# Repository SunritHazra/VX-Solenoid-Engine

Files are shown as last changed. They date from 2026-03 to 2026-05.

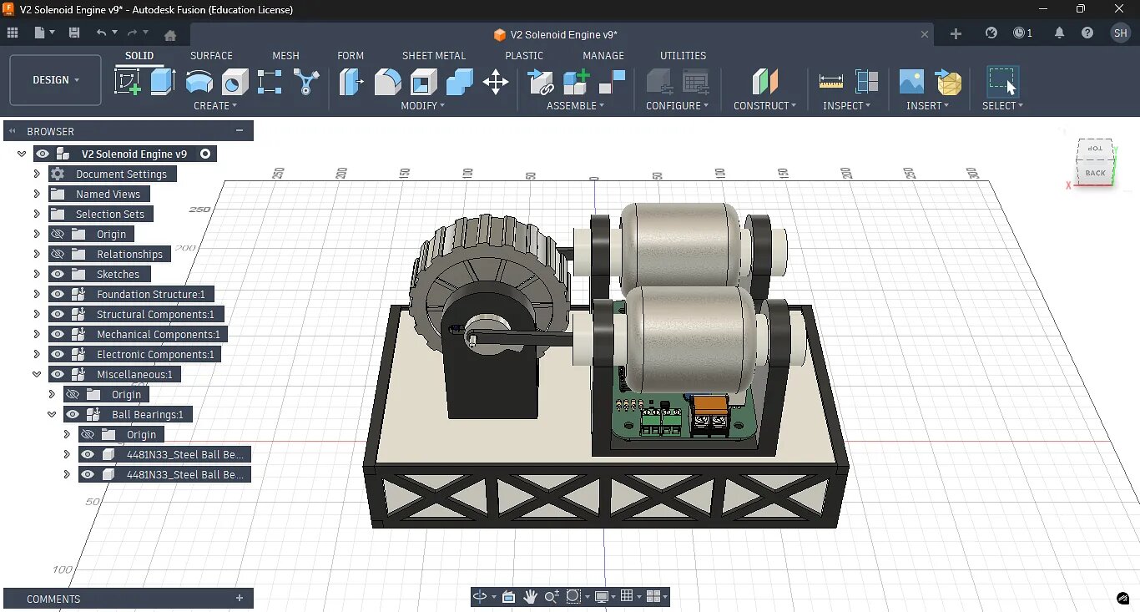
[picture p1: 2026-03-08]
Media/Workspace [2].jpg

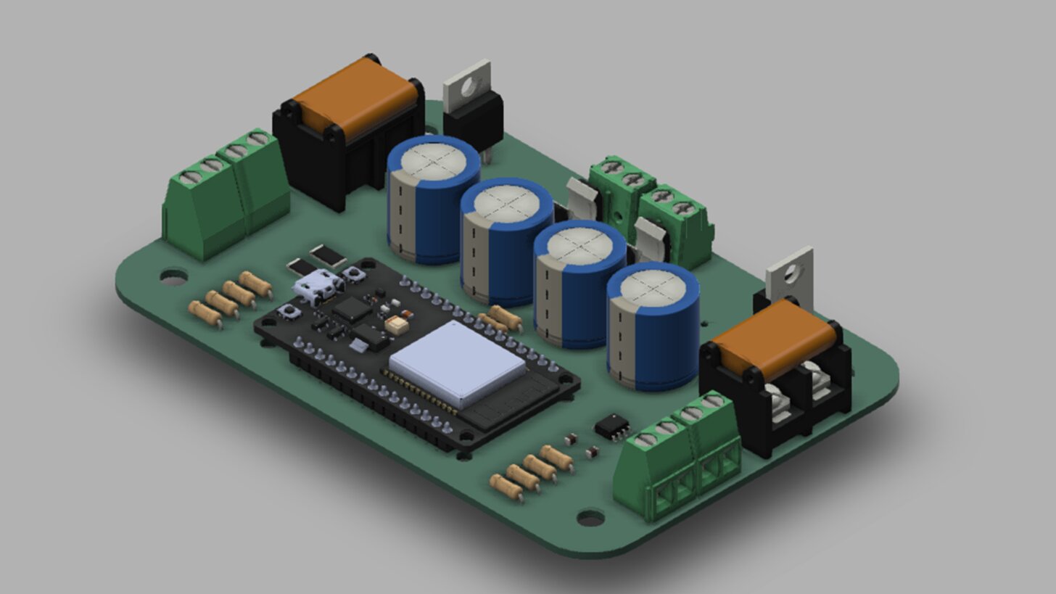
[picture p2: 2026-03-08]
Media/PCBA.jpg

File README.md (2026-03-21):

# VX Solenoid Engine — V2 Solenoid Engine

The project *"V2 Solenoid Engine"* is the second project of the long-term vision of "VX Solenoid Engine", which aims to build progressive solenoid engines with real engineering and proper planning. I have designed and completed the V1 Solenoid Engine before which was the prototype (you can find this in the first journal entry), and I had a partially designed a V10 Solenoid Engine with the help of an engineer from the United Kingdom (UK).

The V2 Solenoid Engine is a custom-designed electromechanical engine that converts electrical energy into rotational mechanical motion using electromagnetic actuation. Instead of combustion, the engine uses solenoids to generate magnetic fields that pull ferromagnetic plungers inside cylindrical sleeves, producing linear motion. This motion is transferred through a yoke and crankshaft mechanism that converts the linear movement into continuous rotation, similar to the working principle of a traditional piston engine.

This project is made with the aim of creating an engine that works efficiently, consistently and with coolness (not talking about thermal coolness), wirelessly. The ESP32 allows the user to run the engine at any speed, control the firing, etcetera. The engine is intended to be controllable through a laptop, a phone or any device wirelessly.

<center>
  V2 Solenoid Engine
</center>

We can often see solenoid engines nowadays as hobby toys, on platforms like YouTube, so what separates this project from those?  
Well, this has a PCB, MOSFET switching based on IR sensors, and it is made with performance and efficiency in mind. Please note that, efficiency is not the goal of this project, and this is an experimental setup to study electromagnetic actuation.

---

## Project Overview

The entire mechanical system is designed in **Autodesk Fusion** and the PCBA was designed in **KiCad**, with structural components and mechanical components (except flywheel) intended for MJF and SLS 3D printing, while control electronics are built around an ESP32-DEVKIT-V1 featuring ESP32-WROOM-32 and TCRT5000 IR position sensing. The engine is powered by a Mean Well LRS-450-24, that gives an output of 24 volts and 18.8 amperes.

The current design features a two-cylinder (V2) configuration sharing a single crankshaft, firing at 180 degrees, which improves rotational balance and reduces dead zones during operation. To control the engine’s timing, infrared reflective sensors monitor the position of the crankshaft and provide feedback to an ESP32 microcontroller, which determines when each solenoid should be energized (when the power should be on). A custom PCB handles the electronics (except the SMPS) required for switching the high-current solenoid coils, integrating MOSFET drivers, power regulation, and sensor interfaces while separating high-power and low-voltage logic systems for stability.

<p float="left">
  
  
</p>

The PCB has two different power inputs: one inputs 5V from a battery and one inputs 24V from the Mean Well LRS-450-24 (18.8 A). There are four more logical inputs (screw terminals): Two (4 pins) for each of the IR Sensor, for A, CATH, COLL and E. And there are two big output screw terminals, for each solenoid.



The PCB has no traces for the components through which 18.8 A flows. So, they have to be soldered pin-to-pin manually with thick wire suitable for that current like 18 AWG. I did this as I didn't want to make the traces too thick, probable to overheating and for safety reasons. And of course, I didn't want to use 2 oz thickness as it is expensive.

Together, the mechanical structure, sensing system, embedded controller, and power electronics form a programmable electromagnetic engine platform that allows experimentation with firing timing, control strategies, and electromechanical system design.

The engine demonstrates:
* Electromagnetic actuation
* Crankshaft-based mechanical power conversion
* Embedded timing control
* Hybrid manufacturing (3D printing + CNC)
* MOSFET Switching

**Note:** The flywheel has to be as heavy as possible, so it is better to CNC machine it despite the cost. A large flywheel is used to stabilize rotational inertia and maintain smooth motion between electromagnetic pulses.

---

## Core Concept

A solenoid is an electromechanical device that generates a magnetic field when current flows through its copper coil. A ferromagnetic plunger inside the solenoid is pulled toward the coil center. I just doubled it so that it looks more cool, and is more loud (really).



In this engine, this is what happens fundamentally:
1. A microcontroller (ESP32) activates the solenoid coil based on the position of the crank
2. Magnetic force pulls the ferromagnetic soft iron plunger
3. The plunger drives the connecting rod connected to the crankshaft
4. The crankshaft rotates
5. A flywheel smooths rotational motion
6. IR sensors detect crank position
7. The controller switches coils again

This cycle produces **continuous rotation**, with two pistons firing periodically at 180 degrees.

---

## Key Features

### Multi-Cylinder Mechanical Layout
The engine uses a **V2 configuration**, where two solenoid-driven cylinders operate on a shared crankshaft. This arrangement improves balance and reduces rotational dead zones, allowing smoother and more continuous motion.

### Electromagnetic Actuation
Each cylinder converts electrical energy into linear mechanical motion.  
Each cylinder contains:
* Copper coil winding
* Ferromagnetic plunger
* Linear motion sleeve

When current flows through the coil, a magnetic field is generated that pulls the plunger inward. The plunger’s movement converts magnetic attraction into controlled mechanical displacement.

### Crankshaft Mechanism
The crankshaft converts the linear motion of the plungers into rotational motion.  
Main components include:
* Crank pins
* Yokes
* Connecting linkages

The crankshaft geometry is intentionally compact and shortened to reduce friction losses and improve overall mechanical efficiency.

### Flywheel Stabilization
A large flywheel is mounted on the crankshaft to stabilize rotation.  
Its functions include:
* Increasing rotational inertia
* Reducing stalling between solenoid pulses
* Smoothing torque output

The flywheel helps maintain continuous rotation even when the solenoids are not actively pulling the plungers.

### Optical Position Sensing
The engine uses TCRT5000 infrared reflective sensors to detect crankshaft position.  
These sensors allow the control system to:
* Identify the rotational phase of the crankshaft
* Trigger solenoids at the correct timing
* Prevent mistimed coil activation

This sensing system transforms the engine from a passive mechanism into an actively controlled electromechanical system.

### Exoskeleton Structural Frame
The engine is supported by a rigid exoskeleton frame that holds the mechanical system together. The frame:
* Maintains alignment of cylinders
* Supports bearings and shaft components
* Prevents structural flexing
* Provides mounting points for sensors and electronics

The exoskeleton also allows modular modifications and easier maintenance.

---

## Mechanical Design

The mechanical system consists of several interacting components that convert electromagnetic actuation into rotational motion.

**Solenoid Cylinder Assembly**  
Each cylinder assembly contains:
* Coil housing
* Copper winding space
* Plunger sleeve
* Linear motion channel

The sleeve guides the plunger along a fixed path and ensures proper alignment during motion.

**Yoke Mechanism**  
The yoke connects the plunger to the crankshaft and transfers the linear motion.  
The yoke geometry was thickened to:
* Increase structural strength
* Provide sufficient space for coil windings
* Reduce mechanical deformation during operation

**Crankshaft**  
The crankshaft assembly includes:
* Crank throws
* Bearing supports
* Shaft core
* Flywheel mount

The crank geometry was designed to minimize rotational inertia and reduce mechanical drag.

**Structural Frame**  
The outer frame forms a rigid skeleton that supports the entire mechanical system.  
It provides mounting locations for:
* Cylinder assemblies
* Sensor placements
* Bearing supports
* Crankshaft alignment

---

## Electronics Architecture

The electronics system coordinates solenoid activation and processes sensor input.

**Microcontroller**  
The engine uses an ESP32 DevKit V1 microcontroller.  
Responsibilities include:
* Reading sensor signals
* Determining crankshaft position
* Controlling solenoid activation timing
* Executing control logic

The microcontroller also enables future expansions such as telemetry and advanced control algorithms.

**Position Sensors**  
Crankshaft position is detected using TCRT5000 IR reflective sensors.  
These sensors detect reflective markers attached to the rotating assembly and provide feedback necessary for correct timing of solenoid activation.

**Power System**  
The solenoid coils require high-current switching.  
The typical power architecture includes:
* 24 V power supply
* MOSFET switching stage
* Flyback protection diodes
* Capacitor banks for current stabilization

These components allow safe and efficient control of the solenoid currents.

---

## Manufacturing Plan

The project uses a hybrid fabrication approach, combining additive manufacturing with CNC machining, to balance cost and quality.

**3D Printed Components**  
Most structural components are designed for 3D printing, including:
* Engine frame
* Coil housings
* Yokes
* Sensor mounts
* Structural supports

Likely materials include:
* PLA for early prototyping
* PETG or ABS for stronger functional parts

**CNC Machined Components**  
Precision mechanical parts are planned to be manufactured using CNC machining, primarily through JLCMC.  
These parts include:
* Crankshaft
* Metal shafts
* Mechanical fasteners
* Possibly the flywheel

CNC machining provides better tolerances, strength, and durability for rotating components.

---

## Bill of Materials

A complete bill of materials is provided in **BOM.csv**.  
**Note:** Cart screenshots for Amazon, JLC, and Robu have been added in the design review already. Certain parts are sourced locally and paid for by the creator. Therefore, it is not possible to provide links for those items, and their costs are not included in the BOM requested from HCB.

---

## Firmware

Firmware source code is located at:  
**Firmware/V2 Solenoid Engine Firmware.cpp**

To flash the firmware:
1. Install the Arduino IDE.
2. Install the ESP32 board package.
3. Open the firmware file.
4. Select the correct ESP32 board and port.
5. Upload the firmware to the microcontroller.

After flashing, disconnect USB if powering externally.  
(For PlatformIO users: platformio.ini is included in the firmware folder.)

---

## Wiring

The full wiring schematic is provided here:  
**Media/V2 Solenoid Engine Schematic and Wiring.pdf**

**External Wiring Summary**  
Mean Well LRS-450-24 (+24V/GND) ─── 18 AWG Red/Black ─── J1 on PCB  
Solenoid + connected to +24V rail  
Solenoid - connected to MOSFET drains (manual 18 AWG)  
TCRT5000 sensors connected to their 4-pin headers (A, CATH, COLL, E) → GPIO34/35  
NTC thermistor connected to GPIO36  

**One very important note (again):** The PCB has no traces for the components through which 18.8 A flows. So, they have to be soldered pin-to-pin manually with thick wire suitable for that current like 18 AWG. I did this as I didn't want to make the traces too thick, probable to overheating and for safety reasons. And of course, I didn't want to use 2 oz thickness as it is expensive.

---

## Assembly and Operation Guide

This guide explains how to assemble, wire, and operate the V2 Solenoid Engine after printing the mechanical parts and manufacturing the PCB. Read the entire document before starting assembly.  
Please note that this guide is not completely reliable as the engine is not manufactured and assembled (as of March, 2026).

**Safety Information**  
This project uses 24V DC power, 18.8 A and contains fast moving mechanical parts.  
Follow these obvious precautions:  
- Never power the system while assembling the mechanical structure.  
- Keep fingers, hair, and loose clothing away from the crankshaft and flywheel while running.  
- Always use a regulated 24V power supply capable of supplying adequate current.  
- Ensure correct polarity when connecting the power supply.  
- Disconnect power immediately if components become excessively hot or behave unexpectedly.  
- Do not run the engine unattended.

**Required Components**  
All required components are listed in the Bill of Materials:  
**Bill of Materials/V2 Bill of Materials.csv**

**Tools Required**  
Typical tools required for assembly include:  
- Hex keys / Allen keys  
- Screwdrivers  
- Small wrench or socket set  
- Soldering iron (if assembling PCB manually)  
- Wire cutters and strippers  
- Threadlocker (recommended for high-vibration components)

**Mechanical Assembly**  
Follow these general steps to assemble the mechanical structure.  
#### 1. Frame Assembly  
- Assemble the main frame using the 3D printed structural parts.  
- Secure all frame pieces using the specified fasteners from the BOM.  
- Ensure the frame is rigid and square.  

#### 2. Crankshaft and Flywheel  
- Install the crankshaft into the frame supports.  
- Attach the flywheel to the crankshaft.  
- Verify that the shaft rotates freely with minimal friction.  

#### 3. Piston and Connecting Rod  
- Attach the connecting rod to the crankshaft.  
- Install the piston assembly.  
- Ensure the piston moves smoothly through its full range of motion.  

#### 4. Solenoid Mounting  
- Mount the solenoid in the designated bracket.  
- Align the solenoid plunger with the piston linkage.  
- Ensure the plunger moves freely and does not bind.  

#### 5. Final Mechanical Check  
- Rotate the crankshaft manually.  
- Confirm the full mechanism moves smoothly.  
- Verify that no parts collide or rub excessively.  

**PCB Installation**  
The PCB design files are located in:  
**PCBA/**  
Files included:  
- KiCad project  
- PCB layout  
- schematic  
- gerbers  
- STEP model  

**PCB Mounting**  
- Secure the PCB to the frame using the provided mounting holes.  
- Ensure the board is isolated from metal surfaces if necessary.  
- Maintain airflow around the board for cooling.  

---

## Operation

After the engine is fully assembled and wired:  
1. Ensure the crankshaft rotates freely.  
2. Verify all wiring connections.  
3. Connect the 24V power supply.  
4. Power the system.  

The firmware will drive the solenoid according to the programmed timing, causing the piston to actuate and rotate the crankshaft.  
The flywheel stabilizes the rotation and maintains momentum between solenoid pulses.

---

## Expected Behavior

When operating correctly:  
- The engine should begin rotating shortly after power is applied.  
- The flywheel should maintain smooth rotational motion.  
- The solenoid should actuate in synchronization with the crankshaft motion.  

Performance depends on:  
- Supply voltage stability  
- Mechanical friction  
- Solenoid characteristics  
- Firmware timing parameters  

---

## Troubleshooting

If the engine does not operate correctly:  

**Engine does not start**  
- Verify 24V power supply is connected.  
- Confirm correct wiring according to the schematic.  
- Ensure firmware was successfully flashed.  

**Solenoid does not activate**  
- Check PCB connections.  
- Verify the solenoid wiring.  
- Confirm correct ESP32 operation.  

**Engine stalls or runs poorly**  
- Inspect mechanical alignment.  
- Check for excessive friction.  
- Ensure solenoid plunger moves freely.  

**Excessive heat**  
- Disconnect power immediately.  
- Inspect wiring and current draw.  
- Verify the solenoid is not being continuously energized.  

---

## Additional Files

Relevant files in the repository:  
- **CAD/V2 Solenoid Engine v10.f3d** — Fusion 360 source model  
- **CAD/V2 Solenoid Engine v10.step** — universal 3D model  
- **PCBA/** — PCB design and manufacturing files  
- **Bill of Materials/V2 Bill of Materials.csv** — full component list  
- **Media/** — renders, PCB images, and wiring diagram  
- **Firmware/V2 Solenoid Engine Firmware.cpp** — ESP32 firmware (untested though)  

---

## Final Notes

Before operating the engine for extended periods, perform several short test runs to ensure mechanical stability and safe electrical behavior, because you are basically playing with 18.8 amperes and 24 volts, just for fun (maybe).  
Regularly inspect fasteners, moving components, and electrical connections to maintain safe operation, cause the thing vibrates, A LOT!
By the way, the safety guidelines are written based on real experience when the V1 Solenoid Engine was built.

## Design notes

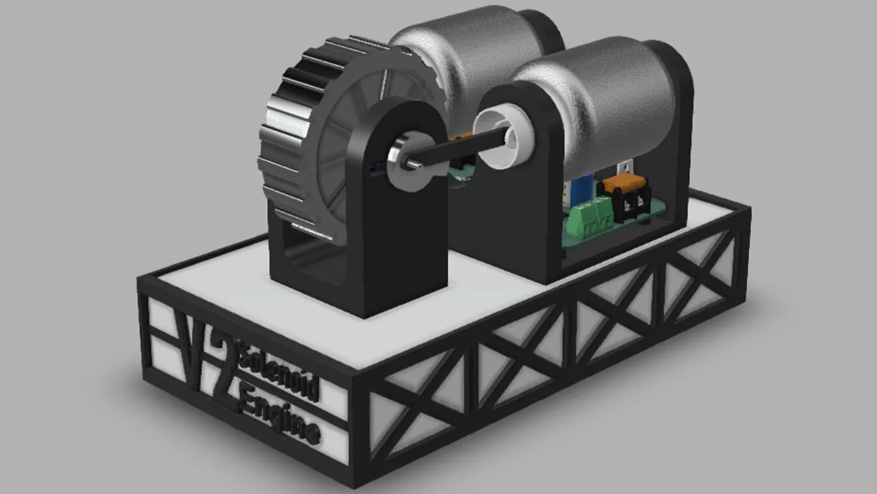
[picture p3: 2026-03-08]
Media/V2 Solenoid Engine — Version 9 Render.jpg

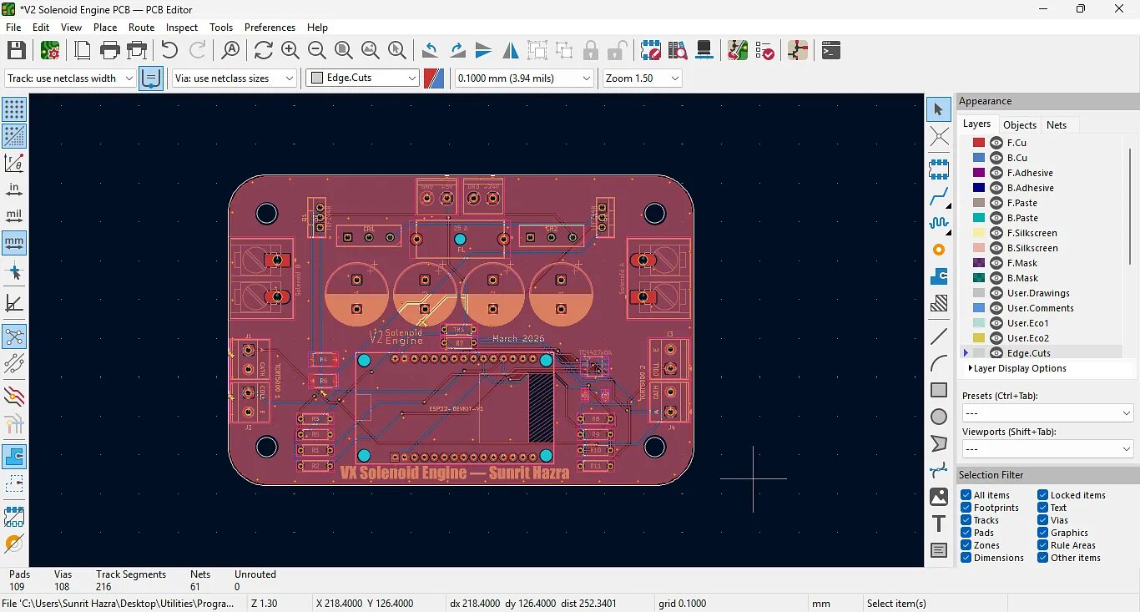
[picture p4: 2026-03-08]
Media/PCB.jpg

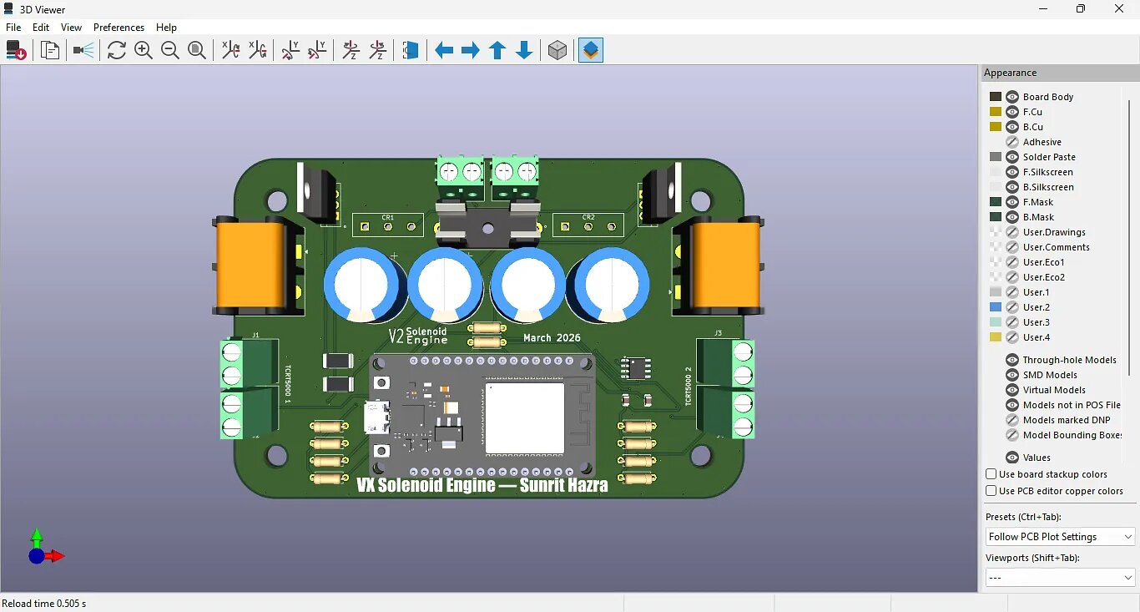
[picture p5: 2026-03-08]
Media/PCB 3D Model.jpg

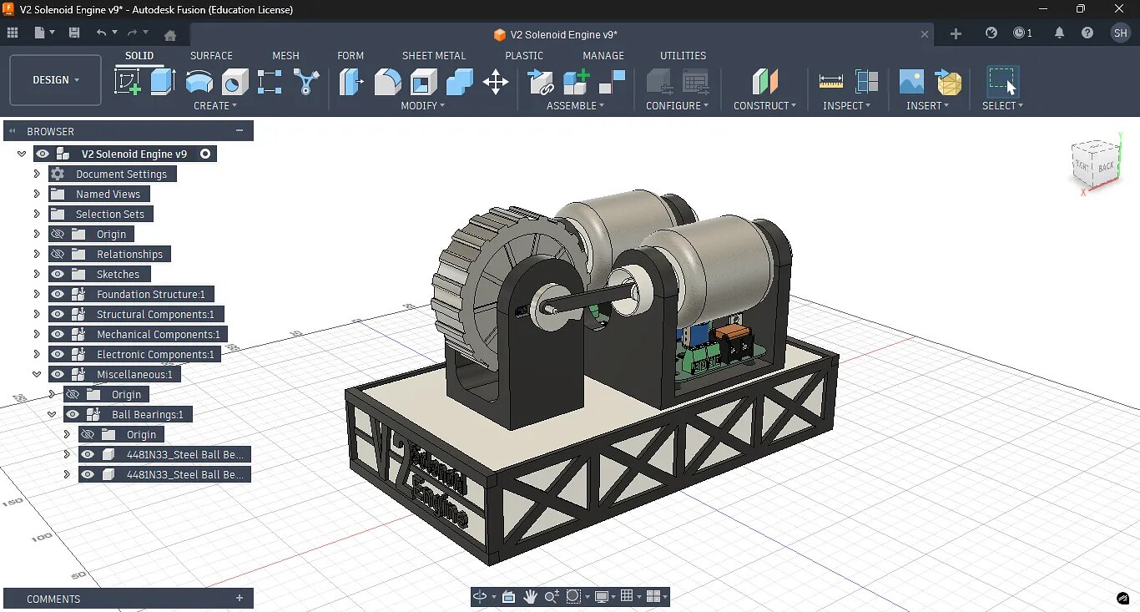
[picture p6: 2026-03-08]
Media/Workspace [1].jpg

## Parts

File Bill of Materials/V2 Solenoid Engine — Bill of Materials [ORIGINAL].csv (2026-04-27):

Component Category | Item | Cost | Side Note | Link
Foundation Structure | Base | $- | I will manufacture this locally using plywood to keep costs low by avoiding laser-cut 5 mm wood.
 | Exoskeleton | $- | I will personally cover the cost of this component.
 |  | $-
Structural Components | Crankshaft Mount | $12.03 | The mount must be very strong as it houses the flywheel, crankshaft, and sensors. | https://jlc3dp.com/3d-printing-quote?spm=Jlc3dp.Homepage
 | Cylinder Mount Lower | $21.13 | The mount must be strong and heat-resistant. | https://jlc3dp.com/3d-printing-quote?spm=Jlc3dp.Homepage
 | Spool Cap A1 | $1.04 |  | https://jlc3dp.com/3d-printing-quote?spm=Jlc3dp.Homepage
 | Spool Cap A2 | $1.04 |  | https://jlc3dp.com/3d-printing-quote?spm=Jlc3dp.Homepage
 | Spool Cap B1 | $1.04 |  | https://jlc3dp.com/3d-printing-quote?spm=Jlc3dp.Homepage
 | Spool Cap B2 | $1.04 |  | https://jlc3dp.com/3d-printing-quote?spm=Jlc3dp.Homepage
 | Cylinder A | $3.81 | These sleeves must be extremely heat-resistant. | https://jlc3dp.com/3d-printing-quote?spm=Jlc3dp.Homepage
 | Cylinder B | $3.81 | These sleeves must be extremely heat-resistant. | https://jlc3dp.com/3d-printing-quote?spm=Jlc3dp.Homepage
 | Mount Cap A1 | $1.04 |  | https://jlc3dp.com/3d-printing-quote?spm=Jlc3dp.Homepage
 | Mount Cap A2 | $1.04 |  | https://jlc3dp.com/3d-printing-quote?spm=Jlc3dp.Homepage
 | Mount Cap B1 | $1.04 |  | https://jlc3dp.com/3d-printing-quote?spm=Jlc3dp.Homepage
 | Mount Cap B2 | $1.04 |  | https://jlc3dp.com/3d-printing-quote?spm=Jlc3dp.Homepage
 | Yoke A | $- | This part requires CNC machining. As the quote was $39.25, I cancelled it to reduce cost (this significantly decreases efficiency).
 | Yoke B | $- | This part requires CNC machining. As the quote was $39.25, I cancelled it to reduce cost (this significantly decreases efficiency).
 |  | $49.10
Mechanical Components | Plunger A | $- | CNC machining would cost $38, so I decided to fabricate it locally instead (this decreases efficiency).
 | Plunger B | $- | CNC machining would cost $38, so I decided to fabricate it locally instead (this decreases efficiency).
 | Piston Head A | $0.94 |  | https://jlc3dp.com/3d-printing-quote?spm=Jlc3dp.Homepage.1006
 | Piston Head B | $0.94 |  | https://jlc3dp.com/3d-printing-quote?spm=Jlc3dp.Homepage.1006
 | Piston Pin A | $- |  | https://jlc3dp.com/3d-printing-quote?spm=Jlc3dp.Homepage.1006
 | Piston Pin B | $- |  | https://jlc3dp.com/3d-printing-quote?spm=Jlc3dp.Homepage.1006
 | Connecting Rod A | $0.94 |  | https://jlc3dp.com/3d-printing-quote?spm=Jlc3dp.Homepage.1006
 | Connecting Rod B | $0.94 |  | https://jlc3dp.com/3d-printing-quote?spm=Jlc3dp.Homepage.1006
 | Crank A | $0.94 |  | https://jlc3dp.com/3d-printing-quote?spm=Jlc3dp.Homepage.1006
 | Crank B | $0.94 |  | https://jlc3dp.com/3d-printing-quote?spm=Jlc3dp.Homepage.1006
 | Axle | $0.94 |  | https://jlc3dp.com/3d-printing-quote?spm=Jlc3dp.Homepage.1006
 | Flywheel | $65.74 | The flywheel ideally needs to be 1.5 kg, but I reduced it to 1 kg to minimize CNC machining cost. | https://www.pcbway.com/rapid-prototyping/manufacture/?type=1
 | Ball Bearings | $0.82 |  | https://robu.in/product/miniature-bearings-625zz
 |  | $73.14
Electronic Components | Mean Well LRS-450-24 | $43.43 | I switched from the Mean Well LRS-600-24 (more expensive) to this model to reduce cost. | https://www.amazon.in/gp/product/B0CH4YY722/ref=ewc_pr_img_1?smid=A13K6Y4N7NSFDR&psc=1
 | Copper Wire [1] | $16.45 | 50 m needed because I want more turns for lower current and reduced heat. | https://www.amazon.in/gp/product/B07GTX1Z32/ref=ewc_pr_img_1?smid=AP7MBNLZTN3FQ&psc=1
 | ESP32-DEVKIT-V1 [1] | $5.45 |  | https://www.amazon.in/gp/product/B071XP56LM/ref=ewc_pr_img_1?smid=AJ6SIZC8YQDZX&psc=1
 | IRLZ44N MOSFET [2] | $1.50 |  | https://robu.in/product/irlz44n/
 | TC4427ACOA Microchip MOSFET Driver [1] | $1.66 |  | https://robu.in/product/tc4427acoa-microchip-mosfet-driver-dual-low-side-non-inverting-4-5v-18v-supply-1-5a-peak-out-7-ohm-output-soic-8/
 | MBR3060PT Lite-On Diode | $2.35 |  | https://robu.in/product/mbr3060pt-liteon-diode-array-1-pair-common-cathode-60-v-30a-through-hole-to-247-3/
 | Rubycon 4700uF 35V Capacitors [4] | $6.86 | Required due to high current. | https://robu.in/product/35px4700mefc16x35-5-rubycon-4700uf-35v-%C2%B120-2-1505a10khz-plugind16xl35-5mm-aluminum-electrolytic-capacitors-leaded-rohs/
 | TCRT5000 Reflective IR Sensor [1 (contains 5)] | $0.60 |  | https://robu.in/product/tcrt5000-reflective-ir-sensor-photoelectric-switch/
 | 2-Pin Barrier Terminal Block Connector 9.5 mm [2] | $1.53 |  | https://www.amazon.in/gp/product/B0B5PK5G92/ref=ewc_pr_img_1?smid=A2JDRZEGU1IDE2&psc=1
 | 2-Pin 5.08 mm Pitch Pluggable Screw Terminal Block [6] | $0.65 |  | https://robu.in/product/2-pin-5-08mm-pitch-pluggable-screw-terminal-block-pack-of-3/
 | V2 Solenoid Engine PCB | $7.80 |  | https://cart.jlcpcb.com/shopcart/cart/
 |  | $88.28
Miscellaneous | JLC3DP Shipping (UPS Worldwide Express Saver) | $36.79 | UPS Worldwide Express Saver is cheaper and faster than E-POST.
 | Amazon Shipping | $- | I will personally cover this cost.
 | Robu.in Shipping | $- | I will personally cover this cost.
 |  | $36.79
Grand Total Price |  |  | $247.31 | Important note: Certain parts are being sourced locally and paid for by the creator. Therefore, it is not possible to provide links for those items, and their costs are not included in the BOM requested from HCB. Cart screenshots for Amazon, JLC, and Robu have been added in the design review already.

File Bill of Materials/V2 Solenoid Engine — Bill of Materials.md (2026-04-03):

| Component Category | Item | Cost | Side Note | Link |
| --- | --- | --- | --- | --- |
| Foundation Structure  | Base | $- | Locally sourced (manufactured using plywood) | |
| | Exoskeleton | $3.23 | | |
| | Total | $3.23 | | |
| Structural Components | Crankshaft Mount | $9.87 | | |
| | Cylinder Mount Lower | $16.90  | | |
| | Mount Caps [4] | $1.56 | | |
| | Cylinders [2] | $4.87 | | |
| | Spool Caps [4] | $2.64 | | |
| | Yokes [2] | $- | This needs CNC, and as it was costing $80, I cancelled it (decreases efficiency significantly) | |
| | Total | $35.84  | | |
| Mechanical Components | Plungers [2] | $- | Doing CNC will cost $76, so I chose to manage it locally instead (decreases efficiency) | |
| | Piston Heads [2] | $1.34 | | |
| | Connecting Rods [2] | $1.34 | | |
| | Crank A | $0.67 | | |
| | Crank B | $0.67 | | |
| | Axle | $0.67 | | |
| | Flywheel Exoskeleton [2] | $2.60 | | |
| | Flywheel Core | $31.81  | | |
| | Ball Bearings [2] | $0.82 | | [Product Link](#) |
| | Total | $39.92  | | |
| Electronic Components | 2 Pin Barrier Terminal Block Connector 9.5 mm [2] | $1.53 | | [Product Link](#) |
| | 35PX4700MEFC16X35.5-Rubycon-4700uF Capacitors [4] | $6.86 | | [Product Link](#) |
| | Copper Wire [5] | $16.45  | | [Product Link](#) |
| | DEGSON DG129-5.08-02P-14-100Z(H) [2] | $0.78 | | [Product Link](#) |
| | Esp-32-DEVKIT-V1 [1] | $5.45 | | [Product Link](#) |
| | IRLZ44N Mosfet [2] | $1.50 | | [Product Link](#) |
| | KANGNEX WJ127-5.0-02P-14-00A [5] | $0.71 | | [Product Link](#) |
| | MBR3060PT-LITEON-Diode [2] | $2.35 | | [Product Link](#) |
| | Mean Well LRS-450-24 | $43.43  | | [Product Link](#) |
| | Milliohm HoJLR2512-3W-10mR-1% [5] | $0.43 | | [Product Link](#) |
| | TC4427ACOA-MICROCHIP-MOSFET Driver [1] | $1.66 | | [Product Link](#) |
| | TORCH CT41G-0805-2X1-50V-0.1uF-K(N) [100] | $0.69 | | [Product Link](#) |
| | V2 Solenoid Engine PCB [5] | $7.80 | | [Product Link](#) |
| | VISHAY TCRT5000L [2] | $3.02 | | [Product Link](#) |
| | Total | $92.66  | | |
| Miscellaneous | Amazon Shipping | $1.30 | Unavoidable | |
| | JLCCNC & JLC3DP Shipping (UPS Worldwide Express Saver) | $36.57  | Cheapest possible option | |
| | JLCPCB Shipping (E-POST) | $10.07  | Cheapest possible option | |
| | LCSC Handling Fee | $3.00 | Unavoidable | |
| | LCSC Shipping (Belgium Post) | $3.88 | Cheapest possible option | |
| | Spray Paint Black | $2.73 | I am buying spary paint, instead of paying for it in JLC (this saves about $2) | [Product Link](#) |
| | Spray Paint White | $2.80 | I am buying spary paint, instead of paying for it in JLC (this saves about $14) | [Product Link](#) |
| | Total | $60.35  | | |
| Grand Total | | $232.00 | | |

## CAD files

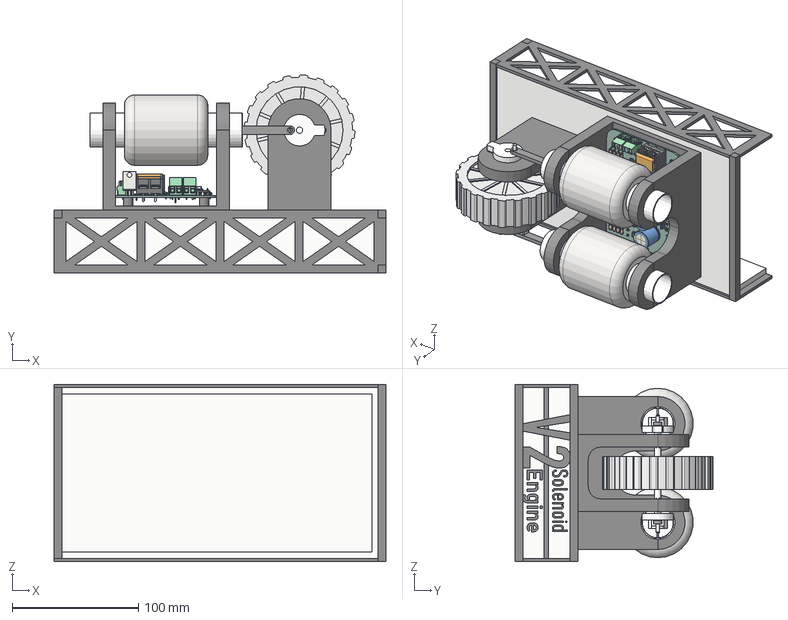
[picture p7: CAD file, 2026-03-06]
CAD/V2 Solenoid Engine v10.step
262.5 x 156.7 x 140.0 mm
F-1036
F-1014
F-1038
F-1029
F-1044
F-1042
F-1047
F-1046
F-1035
F-1019
F-1045
F-1000
F-1043
F-1048
F-1025
F-1022
F-1007
F-1005
F-1015
F-1004
F-1034
F-1009
F-1033
F-1032
Crank B
Crank A
Axle
F-1008
TCRT5000
TCRT5000_1
R_Axial_DIN0207_L6.3mm_D2.5mm_P7.62mm_Horizontal x 10
TerminalBlock_Phoenix_PT-1,5-2-5.0-H_1x02_P5.00mm_Horizontal x 2
TO-220-3_Vertical x 2
TerminalBlock_Phoenix_MKDS-1,5-2_1x02_P5.00mm_Horizontal x 4
R_2512_6332Metric x 2
CP_Radial_D16.0mm_P7.50mm x 4
TerminalBlock_Ningbo-Kagnex_HB9500M_1x02_P9.5mm x 2
C_0805_2012Metric x 2
SOIC-8_3.9x4.9mm_P1.27mm
ESP32-DEVKIT-V1
Fuseholder_Cylinder-5x20mm_Schurter_0031_8201_Horizontal_Open
V2 Solenoid Engine PCB_PCB
4481N33_Steel Ball Bearing
4481N33_Steel Ball Bearing_1

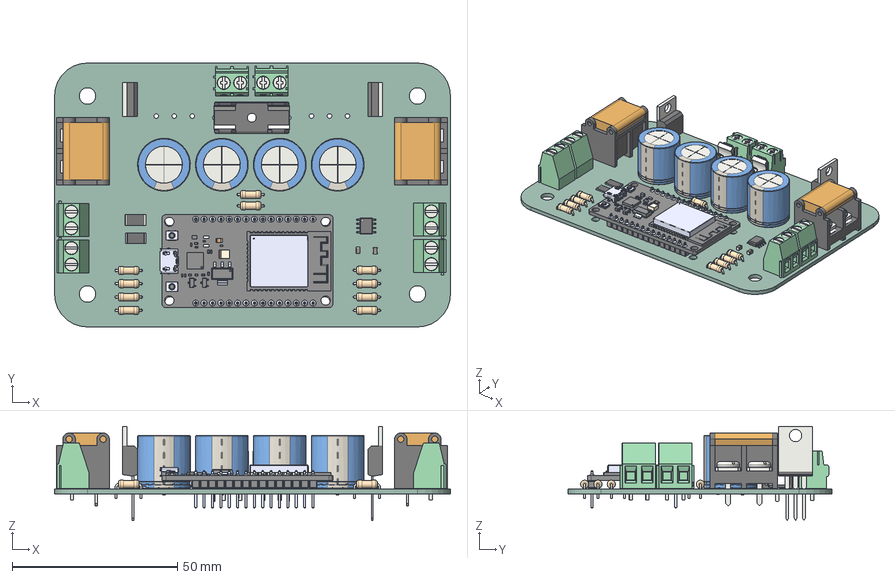
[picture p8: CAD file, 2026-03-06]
PCBA/V2 Solenoid Engine PCB.step
120.0 x 80.0 x 28.5 mm
R_Axial_DIN0207_L6.3mm_D2.5mm_P7.62mm_Horizontal x 10
TerminalBlock_Phoenix_PT-1,5-2-5.0-H_1x02_P5.00mm_Horizontal x 2
TO-220-3_Vertical x 2
TerminalBlock_Phoenix_MKDS-1,5-2_1x02_P5.00mm_Horizontal x 4
R_2512_6332Metric x 2
CP_Radial_D16.0mm_P7.50mm x 4
TerminalBlock_Ningbo-Kagnex_HB9500M_1x02_P9.5mm x 2
C_0805_2012Metric x 2
SOIC-8_3.9x4.9mm_P1.27mm
ESP32-DEVKIT-V1
Fuseholder_Cylinder-5x20mm_Schurter_0031_8201_Horizontal_Open
V2 Solenoid Engine PCB_PCB

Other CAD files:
CAD/V2 Solenoid Engine v10.f3d

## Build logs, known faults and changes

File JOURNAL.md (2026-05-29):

---
**Title:** v2 Solenoid Engine  
**Author:** Sunrit Hazra  
**Description:** The V2 Solenoid Engine is a custom-designed electromechanical engine that converts electrical energy into rotational mechanical motion using electromagnetic actuation.
**Created on:** 29-05-2026
**Progress (%): 25%**
---

# Day X — DD.MM.YYYY: XYZ

**Total time spent: 0h 0m**

---

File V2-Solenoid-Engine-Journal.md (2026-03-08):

<!--
  This journal is auto generated by Hack Club Blueprint.
-->

# 2/9/2026 - Retrospective Journal Entry — V1 Solenoid Engine  

_Time spent: 50.8h_  

This journal entry documents the retrospective development of my completed hardware project, the **V1 Solenoid Engine**, which was built between **August 2025 and January 2026**. Although the project was completed before I joined Hack Club Blueprint, this entry serves to formally log the work, timeline, and effort invested into a shipped electromechanical system.

---

## Entry Date: 09.02.2026

Today, I officially logged into Hack Club, signed up for Blueprint, and got officially approved. I explored the entire platform and was intrigued by everything it offers. While thinking of projects, I realized that I had already completed a hardware project with my friend last month (on **Jan 13, 2026**) — the **V1 Solenoid Engine**, which I originally started in **August 2025**.

---

## The V1 Solenoid Engine

V1 Solenoid Engine Snapshot

---

## Flashback

I wanted to make a **V10 Solenoid Engine** ever since I came across the fascinating concept of solenoids and solenoid engines producing electromagnetic actuation back in **September 2024**. I began working on it with the help of an engineer from the UK and self-learned **Autodesk Fusion** (leveraging my prior experience with Blender).

As things progressed, I was selected for a **national-level round of the STEAM Innovation League**, solely based on the idea itself. I also signed up for **Autodesk Instructables**. However, despite nearly completing the entire design (except PCBs), the project lacked practicality due to its high cost, which I was unable to fund.

So why didn’t I think about funding earlier?
That was paradoxical — to be precise about cost, I first had to build it.

Did I waste my time?
Absolutely not.

This realization led to the idea of a **V1 Solenoid Engine**, a prototype. That decision gave birth to the engine.

---

## Early Development

**Aug 02, 2025 (Morning)**
This was my friend **Soumajit’s birthday**. He later became crucial to the project and is the reason the engine works today. I initially planned to build the V1 Solenoid Engine and began gathering components, but soon decided to model it first.

**Aug 15, 2025 – 4:10 PM**
My school physics teacher, who was interested in the project, bought the most expensive components: **10 neodymium magnets (25 mm × 3 mm)**. They arrived within a week.

**Aug 16, 2025 – 7:03 PM**
I officially started modeling the **V1 Solenoid Engine** in Autodesk Fusion. At the same time, I contacted the owner of a local factory that manufactures plywood production machinery. He agreed to machine parts free of cost, provided they were not overly complex.

**Aug 17, 2025 – 4:08 PM**
The **Mechanical Components Drawing** was completed with all required dimensions. It was approved except for the piston head (due to high tolerances and complexity). The machined parts arrived within a week.

---

## Assembly and Iteration

**Aug 23, 2025 – 5:30 PM**
I completed modeling the **Piston Pin** and finalized the assembly joints and animation. This was a major success, as I had previously struggled with assembly animation in the V10 project.

**Aug 29, 2025 – 3:52 PM**
I began re-modeling the **Piston Head**, realizing it had to be 3D printed. I contacted a local 3D printing service — the same one I had earlier approached for V10 — and faced a major cost reality check. The print arrived the next day.

**Aug 30, 2025 – 6:00 PM**
I received the print. I glued the magnets to the flat end of the piston head, coupled the connecting rod using bamboo skewers, and sanded the crank and flywheel smooth.

---

## Pause and Resume

With exams approaching, the project paused. During this period, I purchased bearings online and sourced a PVC pipe for the piston cylinder from a hardware shop.

**Dec 01, 2025 – 5:00 PM**
I completed the **Structural Components Setup** in Autodesk Fusion and sliced it using **Bambu Studio**. Our school had recently acquired **Bambu Lab H2D** and **Bambu Lab A1** printers, making it the perfect opportunity to print the remaining components.

**Dec 19, 2025 – 11:30 AM**
I received the printed structural components. This marked the moment when a long-thought, abstract idea became concrete reality. I assembled the axle, flywheel, crank, solenoid cylinder with copper windings, piston with magnets, pivots, and connecting rod. The engine could now be manually operated.

I tested electrical actuation using a relay and a low-voltage triple Li-ion battery (~8V). I observed partial motion, sparks, and semi-actuation. Seeing this confirmed that the concept worked. Exhausted, I went to sleep knowing it had to be completed.

---

## Bringing It to Life

**Dec 20, 2025 – 8:00 AM**
I worked solely on the solenoid engine. Manual actuation worked, the cam and switch were attached, but I realized the solenoid had only ~120 turns instead of the required ~300. Power was unreliable. We needed an SMPS. Soumajit arranged a **Mean Well LRS-350-24** from school.

**Dec 21, 2025 – 1:20 PM**
The engine worked. Fully.
Credit goes to **Soumajit Giri**, who properly fixed the mechanical switch.

**Dec 22, 2025 – 3:00 PM**
I cleaned and refined the build: corrected holes, removed glue, replaced wiring, mounted the SMPS and switch properly using screws. However, the engine failed again — the switch was rated for **10 A**, while the SMPS delivered **14.6 A**.

---

## Final Fix and Completion

After winter vacation and travel,

**Jan 09, 2026 – 2:20 PM**
My physics teacher bought **16 A mechanical switches**.

**Jan 13, 2026 – 3:30 PM**
The new switch was installed, and the **V1 Solenoid Engine worked better than ever before**. Project officially completed.

---

## Working Video

[[V1 Solenoid Engine 2026-02-09](https://chatgpt.com/user-attachments/blobs/proxy/eyJfcmFpbHMiOnsiZGF0YSI6MTAxMjA3LCJwdXIiOiJibG9iX2lkIn19--69a06a216f94585c77eb3a04e2dc9698bab4b164/V1%20Solenoid%20E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)](/user-attachments/blobs/proxy/eyJfcmFpbHMiOnsiZGF0YSI6MTAxMjA3LCJwdXIiOiJibG9iX2lkIn19--69a06a216f94585c77eb3a04e2dc9698bab4b164/V1%20Solenoid%20Engine%202026-02-09.mp4)

---

## Workspace Snapshots

Autodesk Fusion Teams Snapshot 2026-02-09 214807

Autodesk Fusion Workspace Snapshot 2026-02-09 214503

---

# 2/17/2026 - Engineering Development Log — V2 Solenoid Engine (v1 → v7)  

_Time spent: 15.7h_  

**Author:** Sunrit Hazra
**Timeframe:** 10-02-2026 → 16-02-2026
**Version Span:** Version 1 to Version 7

*[Note: Lowercase 'v' represents 'version', and uppercase 'V' represents the number of cylinders which stays consistent as two cylinders (V2).]*

---

## Journal Log Overview

This log documents the structured development of the V2 solenoid engine across seven design versions (v1–v7). The progression moves from mechanical replication to structural optimization, magnetic circuit refinement, and preparation for sensor-based electronic control. Each version addresses a specific engineering layer: geometry, kinematics, load stability, electromagnetic actuation, flux management, and rotational inertia.

---

## V2 Solenoid Engine — v7 (latest as of 16-02-2026)



---

## v1 — Direct Replication  
**10-02-2026 | 01:00 AM**

The project began with an exact copy of the V1 Solenoid Engine v14. No geometry was altered.

Mechanical elements present:
- Single piston–sleeve assembly  
- Crank and connecting rod  
- Structural supports  
- Basic flywheel  

Objectives:
- Understand mechanical proportions.
- Study crank radius to stroke relationship.
- Observe piston guidance inside the sleeve.
- Analyze support placement and constraint hierarchy.

At this stage, the system remained magnet-based (neodymium plunger). The purpose was familiarization, not improvement.

### V2 Solenoid Engine — v1



### V2 Solenoid Engine — v1 (without Structural Components)



---

## v2 — Conversion to V2 (Bilateral Symmetry, 180° Phasing)  
**10-02-2026 | 11:29 AM**

The entire mechanical assembly was duplicated symmetrically across the crank axis to create a two-cylinder configuration (V2).

Components duplicated:
- Pistons  
- Cylinders (sleeves)  
- Connecting rods  
- Crank throws  
- Cylinder supports  
- Crankshaft support structure  

A solid flywheel replaced the previous design.

Engineering impact:
- 180° firing separation introduced.
- Torque pulses distributed across rotation.
- Reduced rotational dead zones.
- Improved angular continuity.

The crank geometry was adjusted to maintain exact phase opposition between cylinders. Structural supports were widened to accommodate bilateral loading.

The engine transitioned from single impulse motion to phased rotational architecture.

### V2 Solenoid Engine — v2



### V2 Solenoid Engine — v2 (without Structural Components)



---

## v3 — Motion Definition and Flywheel Redesign  
**10-02-2026 | 01:04 PM**

Motion constraints were implemented within the assembly.

Actions performed:
- Revolute joint added to crankshaft.
- Slider constraints applied to pistons.
- Connecting rod linkages validated.
- Full rotational motion simulated.

Interference checks were performed through manual rotation and motion study.

A new flywheel was modeled:
- Increased mass relative to v2.
- Designed with symmetric extrusion features.
- Modular geometry allowed weight adjustment without scaling diameter.
- Central bore tolerance refined.

Structural supports were strengthened slightly to manage the increased inertial load from the heavier flywheel.

This version confirmed:
- Smooth kinematic operation.
- No collision under full rotation.
- Balanced mechanical motion.

### V2 Solenoid Engine — v3



### V2 Solenoid Engine — v3 (without Structural Components)



---

## v4 — Structural Reinforcement Phase  
**10-02-2026 → 12-02-2026**

The structural system was reinforced for durability.

Modifications:
- Thickened cylinder mounts.
- Increased cross-sectional area of support arms.
- Strengthened crankshaft support walls.
- Adjusted base plate thickness.
- Improved alignment between structural pillars.

Focus areas:
- Load path from piston force to base.
- Crankshaft bearing stability.
- Prevention of torsional flex under load.

This phase emphasized structural rigidity and alignment accuracy rather than performance increase.

The engine geometry became more compact and mechanically cohesive.

### V2 Solenoid Engine — v4



### V2 Solenoid Engine — v4 (without Structural Components)



---

## v5 — Electromagnetic Redesign  
**12-02-2026 | 11:28 AM**

A fundamental redesign of the actuation mechanism occurred.

Change implemented:
- Replaced neodymium magnet plungers with AISI 1018 soft iron plungers.

Engineering reasoning:
- Permanent magnets introduce asymmetric bias forces.
- Soft iron allows purely field-controlled actuation.
- Enables independent electronic timing control.
- Reduces uncontrolled attraction during idle.

Additional modifications:
- Crank radius slightly reduced to lower mechanical losses.
- Crankshaft length shortened.
- Sleeve walls made thinner.
- Yokes introduced.
- Flywheel mass increased.
- Exoskeleton structure added.

Motion constraints were revalidated after geometry changes.

This version marked the transition to controlled electromagnetic actuation.

### V2 Solenoid Engine — v5



### V2 Solenoid Engine — v5 (without Structural Components)



---

## v6 — Thickened Yoke and Magnetic Circuit Optimization  
**12-02-2026 | 07:02 PM**

Magnetic circuit geometry was refined to improve performance under higher current.

Changes:
- Yoke thickness significantly increased.
- Additional space created for copper windings.
- Sleeve length increased.
- Overall structure made more compact.
- Component spacing reduced to minimize magnetic path gaps.

Engineering intent:
- Reduce magnetic saturation.
- Improve flux continuity.
- Increase available ampere-turn capacity.
- Enhance force density at equivalent current.
- Improve mechanical stiffness due to compaction.

The magnetic path from coil → yoke → plunger → return path was shortened and thickened.

This version focused primarily on electromagnetic efficiency.

### V2 Solenoid Engine — v6



### V2 Solenoid Engine — v6 (without Structural Components)



---

## v7 — Crankshaft Extrusions and Inertia Management  
**16-02-2026 | 05:41 PM**

Crankshaft extrusions were added.

Modifications:
- Added symmetric mass features to crank arms.
- Increased rotational stability.
- Light counterweighting effect introduced.
- Structural reinforcement at crank joints.
- Provided surfaces for potential electronics mounting.

Purpose:
- Reduce angular velocity fluctuation.
- Prepare system for alternating 180° firing.
- Improve mechanical durability.
- Create foundation for sensor-based integration.

This version is mechanically incomplete but strategically positioned for electronics implementation.

### V2 Solenoid Engine — v7



### V2 Solenoid Engine — v7 (without Structural Components)



---

## Technical Boundary Between Versions

| Versions | Plunger Type | Control Method |
|---|---|---|
| v1–v4 | Neodymium Magnet | Passive Magnetic |
| v5–v7 | AISI 1018 Soft Iron | Electromagnetic Control |

This boundary represents the transition from magnetic attraction to programmable field actuation.

---

## Current System State (End of v7)

Mechanical:
- Dual-cylinder (V2) architecture.
- 180° crank separation.
- Reinforced structural supports.
- Thickened yoke magnetic circuit.
- Adjustable-mass flywheel.
- Improved crank inertia distribution.

Electromagnetic:
- Soft iron plunger system.
- Increased coil volume capacity.
- Reduced magnetic saturation risk.
- Compact flux path geometry.

Prepared For:
- IR sensor-based crank position detection.
- Independent 180° firing control.
- MOSFET-based low-side switching.
- ESP32-based programmable timing.

---

## Development Pattern Observed

The progression follows a layered engineering sequence:

1. Mechanical replication.
2. Symmetry and phasing introduction.
3. Kinematic validation.
4. Structural reinforcement.
5. Electromagnetic transition.
6. Magnetic efficiency optimization.
7. Rotational inertia refinement.

Each stage builds on the stability of the previous one.

---

## Next Engineering Domain

The mechanical and magnetic platform is stabilized.

The next domain is timing precision:
- Sensor-triggered firing.
- Independent cylinder control.
- Adjustable dwell.
- RPM-responsive advance.
- Thermal monitoring and current control.

At this stage, performance improvements will come primarily from timing optimization rather than geometric redesign.

---

## Summary

Between 10-02-2026 and 16-02-2026, the V2 solenoid engine evolved from a replicated magnetic demonstrator into a structured electromagnetic platform ready for programmable control.

Seven versions addressed:
- Geometry.
- Symmetry.
- Motion validation.
- Structural strength.
- Actuation physics.
- Magnetic efficiency.
- Rotational inertia.

The engine is now mechanically mature and prepared for controlled electronic integration.

# 3/6/2026 - Engineering Development Log — V2 Solenoid Engine (v8 → v9)  

_Time spent: 54.0h_  

**Author:** Sunrit Hazra  
**Timeframe:** 17-02-2026 → 06-03-2026  
**Version Span:** Version 8 to Version 9  

*[Note: Lowercase 'v' represents 'version', and uppercase 'V' represents the number of cylinders, which remains consistent as two cylinders (V2).]*

---

## Journal Log Overview

This entry documents the continuation of the V2 solenoid engine development beyond v7. While earlier versions focused on mechanical architecture, structural reinforcement, magnetic circuit optimization, and crankshaft inertia balancing, the next stage begins the integration of sensing and control infrastructure.

Versions v8 and v9 move the project closer to a functional electronically controlled electromagnetic engine. These versions introduce sensor mounting geometry and initial layout considerations required for real-world control systems.

Rather than large structural redesigns, these versions focus on preparing the mechanical platform for **sensor-based crank position detection**, **electronic timing**, and **external interfacing**.

---

# V2 Solenoid Engine — v9 (latest as of 06-03-2026)



---

# v8 — Sensor Integration Preparation  
**24-02-2026 | 06:58 PM**

Version 8 introduced preliminary features required for the upcoming control system and sensor integration. While the mechanical architecture of the engine remained largely unchanged from the previous version, several small but meaningful adjustments were implemented to prepare the design for optical sensing and electronic control.

The first addition was a **text engraving on the structural frame displaying “V2 Solenoid Engine.”** This serves as both a visual identifier for the project and a small design refinement that reinforces the identity of the engine within the model itself.

More importantly, **mounting holes were introduced to house infrared reflective sensors**, specifically the **TCRT5000 IR sensors**. These sensors are intended to detect crankshaft position by reading reflective markers on the rotating assembly. Their inclusion marks the beginning of the transition from a purely electromechanical experiment to a system capable of **electronically timed firing control**.

The holes were placed along the structural frame in positions where the sensors could observe the crankshaft region without interfering with the mechanical motion of the pistons or connecting rods. At this stage, the holes were simple cylindrical cutouts intended primarily as placeholders for later refinement.

Version 8 therefore served as a **preparatory stage**, introducing the first structural provisions required for sensor integration while preserving the stability and geometry established in earlier iterations.

### V2 Solenoid Engine — v8





### V2 Solenoid Engine — v8 (without Mechanical Components)



---

# v9 — Sensor Integration, Mechanical Refinement, and Control Electronics  
**06-03-2026 | 10:00 AM**

Version 9 represents a major step forward for the V2 solenoid engine. This version introduced developments across three key domains:

- Sensor integration  
- Mechanical refinement  
- Dedicated electronic control system development  

Together, these changes begin bridging the gap between a mechanical prototype and a programmable electromagnetic engine.

---

## Sensor Mounting and Optical Detection Improvements

One of the first modifications in this version involved refining the sensor mounting geometry introduced in Version 8.

The previously added sensor holes were **flipped in orientation** to reduce unwanted signal reflections. During evaluation it became apparent that the **connecting rod could reflect infrared light**, potentially producing false detection signals. By reversing the sensor orientation, the reflective detection path was directed more precisely toward the crankshaft detection region.

To ensure accurate placement, the **3D model of the TCRT5000 IR sensor was imported directly into the CAD assembly**. The structural frame was then carved using the exact geometry of the sensor model, producing a cavity that matches the sensor's shape and dimensions. This method ensured a precise mechanical fit and correct optical alignment between the emitter and receiver components.

This approach provided several advantages:

- Accurate sensor positioning  
- Improved signal reliability  
- Reduced alignment adjustments during assembly  

The resulting mounting structure holds the sensors securely while maintaining correct detection geometry relative to the rotating crank assembly.

---

## Solenoid Spacing Adjustment

To accommodate the sensors and their wiring more effectively, the spacing between the two solenoid assemblies was increased slightly. This modification created additional clearance within the central region of the engine frame.

The added space allows for:

- Sensor installation  
- Cable routing  
- Improved accessibility for assembly and maintenance  

It also reduces the likelihood of mechanical interference between moving parts and sensor wiring.

---

## Axle Extension

Because the structural width of the engine increased slightly due to the new sensor placement and solenoid spacing, the **crankshaft axle length was extended**. The longer axle maintains proper alignment between the crankshaft, flywheel, and bearing supports while preserving the balanced geometry of the system.

---

## Bearing System Revision

The bearing configuration used in earlier versions was revised to simplify assembly and improve compatibility with the printed structural components.

The previous design used:

**6153K26 — Corrosion-Resistant 440C Stainless Steel Ball Bearing**

This was replaced with:

**4481N33 — Steel Ball Bearing**

The updated bearing offers more standard dimensions and integrates more easily into the printed housing geometry.

A **dedicated bearing seating section** was designed into the structure. This cavity allows the bearings to fit tightly within the frame with little or no adhesive required. The geometry provides sufficient support to maintain alignment while reducing the need for glue or external fasteners.

This decision simplifies assembly and allows bearings to be replaced more easily if maintenance becomes necessary.

---

## Development of the Electronic Control System

Version 9 also marks the introduction of a **custom electronic control system** designed specifically for the V2 solenoid engine.

For the first time in the project, a **custom PCB was designed using KiCad (version 9.0.7)**. Learning the software required significant effort, and the design process involved several iterations of both the schematic and the board layout.

In total, approximately **40 hours of work** were invested in developing the electronics system.

The final design resulted in a **two-layer printed circuit board measuring approximately 210 mm × 140 mm**, intended for fabrication through standard PCB manufacturing services.

---

## Power Supply Revision

During the design process, the main power supply for the engine was revised.

The previous power supply was:

**Mean Well LRS-600-24**

This was replaced with:

**Mean Well LRS-450-24**

The updated supply still provides a stable **24 V output capable of high current**, which is sufficient for driving the solenoid coils used in the engine.

The electrical system operates using two separate voltage domains:

**24 V Power Rail**

This rail powers the solenoid coils and handles the high-current pulses generated during engine operation.

**5 V Logic Rail**

This rail powers the microcontroller and low-power electronics.

Separating these two rails helps maintain stable operation of the logic system even during high-current switching events.

---

## Microcontroller Platform Change

The original plan was to use the **ESP32-WROOM-32 module** directly.

During development this was changed to the **ESP32-DevKit-V1 development board**, which offers several practical advantages during prototyping and testing:

- Built-in USB interface  
- Integrated voltage regulation  
- Simplified programming and debugging  

The ESP32 will control solenoid timing, process sensor input signals, and allow programmable adjustments to the engine’s firing sequence.

---

## High Current Handling Strategy

Early versions of the PCB attempted to route **approximately 18.8 amps** directly through PCB copper traces. After evaluating the current-handling limits of standard copper layers, this approach was abandoned.

Instead, a safer strategy was adopted.

High-current paths will **not run through PCB traces**. These connections will instead be implemented using **18 AWG silicone insulated wires**, soldered directly between components after PCB assembly.

This approach:

- Prevents overheating of PCB traces  
- Eliminates risk of copper delamination  
- Allows flexible routing for high-current paths  

Only control signals and low-current power lines remain on the PCB itself.

---

## PCB Architecture

The board layout is divided into three functional zones to improve reliability and reduce electrical noise.

### Power Zone

This section handles the main 24 V input and energy buffering for solenoid operation.

Components include:

- Input power connector  
- 25 A fuse  
- Large electrolytic capacitor bank (4700 µF)  
- MOSFET switching devices  
- Flyback protection diodes  

---

### Driver Zone

The driver zone contains circuitry responsible for switching the MOSFETs efficiently.

Primary component:

**TC4427A Dual MOSFET Gate Driver**

This device provides strong gate drive current, ensuring fast switching transitions that reduce switching losses.

---

### Logic Zone

The logic zone contains the microcontroller and sensor interface electronics.

Key components include:

- ESP32-DevKit-V1  
- TCRT5000 sensor connections  
- Buck regulators for logic voltage generation  
- Pull-up resistors and signal conditioning components  

Separating the logic electronics from the high-current switching components helps reduce electromagnetic interference and improves signal stability.

---

## Solenoid Driver Circuit

Each solenoid coil is driven by a MOSFET switching stage consisting of:

- **IRFZ44N MOSFETs**  
- **TC4427A gate driver**  
- **MBR3060PT flyback diodes**

The MOSFETs switch the ground path of the solenoids while the positive side remains connected to the 24 V supply.

Flyback diodes are placed across the solenoid coils to safely dissipate voltage spikes generated when the magnetic field collapses after switching.

---

## Sensor System

Two **TCRT5000 infrared reflective sensors** detect crankshaft position.

These sensors read reflective targets attached to the rotating assembly. Their signals are routed to **ESP32 GPIO pins 34 and 35**, which are input-only pins well suited for interrupt-based detection.

Pull-up resistors are used to ensure stable digital signals.

---

## Grounding Strategy

The PCB uses a **star grounding topology**.

Two ground domains are defined:

- Power Ground (PWR_GND)  
- Logic Ground (LOGIC_GND)

These meet at a single junction near the power input connector. This arrangement prevents high-current switching noise from propagating into the microcontroller and sensor circuitry.

---

## PCB Layout Characteristics

The completed PCB design includes the following characteristics:

- Two-layer board  
- 1 oz copper thickness  
- Minimum clearance: 0.25 mm  
- Signal trace width: 0.25 mm  
- Wider traces for moderate power routing  
- Full ground plane on the bottom layer  

Additional design features include:

- 109 plated through holes  
- 4 mounting holes for M3 screws  
- Enlarged solder pads for manual high-current wiring  

Both **Electrical Rule Check (ERC)** and **Design Rule Check (DRC)** passed successfully without violations.

---

## Functional Overview

The PCB performs several key functions within the engine system:

- Detect crankshaft position using infrared sensors  
- Generate PWM timing signals through the ESP32  
- Drive MOSFET switches through the TC4427A gate driver  
- Control two high-power solenoid coils  
- Monitor system temperature using an NTC thermistor  
- Provide programmable timing control via firmware  

Manual high-current wiring connects the MOSFET stage to the power supply and solenoid coils.

---

## Significance of Version 9

Version 9 represents a turning point in the development of the V2 solenoid engine.

Earlier versions focused primarily on mechanical structure and magnetic actuation. With the introduction of sensors and a dedicated control PCB, the system evolves into a **programmable electromagnetic engine platform**.

The project now integrates:

- Optical crankshaft sensing  
- Microcontroller-based timing control  
- High-current MOSFET switching electronics  
- Custom PCB hardware  

These developments establish the foundation for experimentation with firing timing, efficiency tuning, and closed-loop control strategies.

---

### V2 Solenoid Engine — v9





### V2 Solenoid Engine — v9 PCBA 3D Model



### V2 Solenoid Engine — v9 PCB



---

## Plunger System Boundary

| Versions | Plunger Type |
|---|---|
| v1 – v4 | Neodymium Magnet |
| v5 – v9 | AISI 1018 Soft Iron |

---

## Mechanical Configuration (v9)

**Cylinder System**
- Two piston assemblies  
- Two sleeves  
- Two connecting rods  

**Crank System**
- Single crankshaft  
- Dual crank throws  
- Extruded crank arms  

**Rotational System**
- Heavy flywheel  

**Magnetic Components**
- Soft iron plungers  
- Magnetic yokes  
- Sleeve-mounted coil space  

**Structural System**
- Reinforced cylinder supports  
- Crankshaft support structure  
- Exoskeleton frame  

**Sensor Mounting**
- Four TCRT5000 IR sensor holes  

---

## Development Sequence Observed

The design evolved through the following stages:

1. Replication of the original engine  
2. Expansion to a two-cylinder architecture  
3. Motion simulation and flywheel redesign  
4. Structural reinforcement  
5. Mechanical and electromagnetic redesign  
6. Magnetic yoke strengthening and compact layout  
7. Crankshaft mass additions  
8. Sensor mounting preparation  
9. Expanded sensor mounting capability  

---

## Summary

Between **10 February 2026 and 06 March 2026**, the V2 solenoid engine progressed from a replicated single-cylinder model into a reinforced two-cylinder electromagnetic engine structure with integrated provisions for infrared sensor mounting and electronic control.

Across **nine versions**, the work included:

- conversion to a two-cylinder architecture  
- flywheel redesign  
- structural reinforcement  
- introduction of magnetic yokes  
- replacement of magnet plungers with soft iron plungers  
- compaction of the engine structure  
- crankshaft mass additions  
- mounting provisions for IR sensors  
- development of a custom electronic control system  

The current model (**v9**) represents the latest mechanical and electronic configuration created during this development period.

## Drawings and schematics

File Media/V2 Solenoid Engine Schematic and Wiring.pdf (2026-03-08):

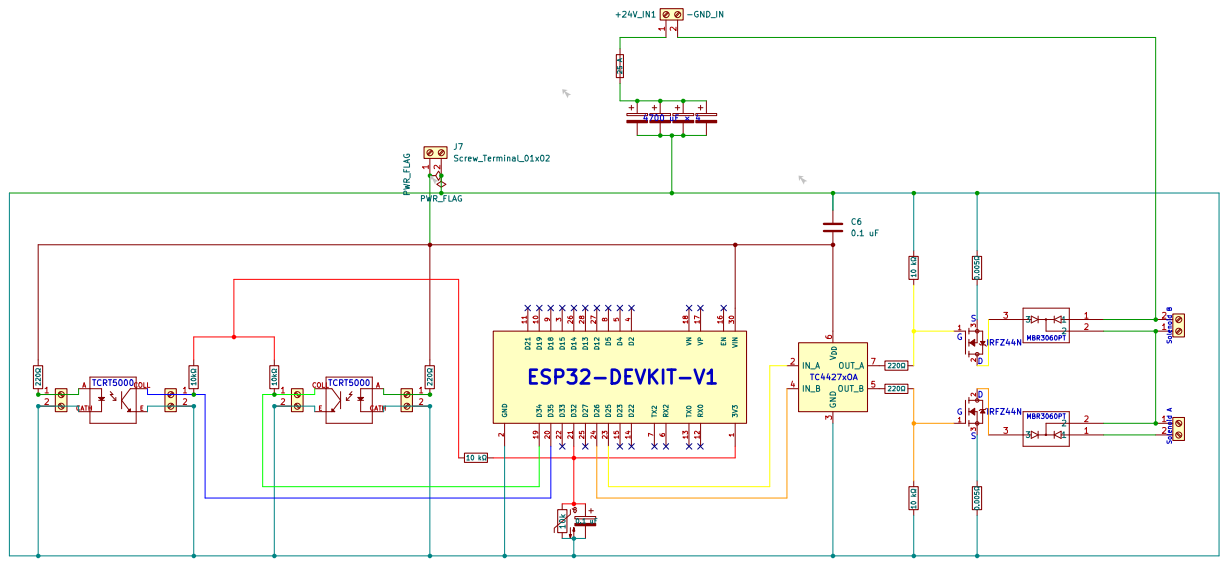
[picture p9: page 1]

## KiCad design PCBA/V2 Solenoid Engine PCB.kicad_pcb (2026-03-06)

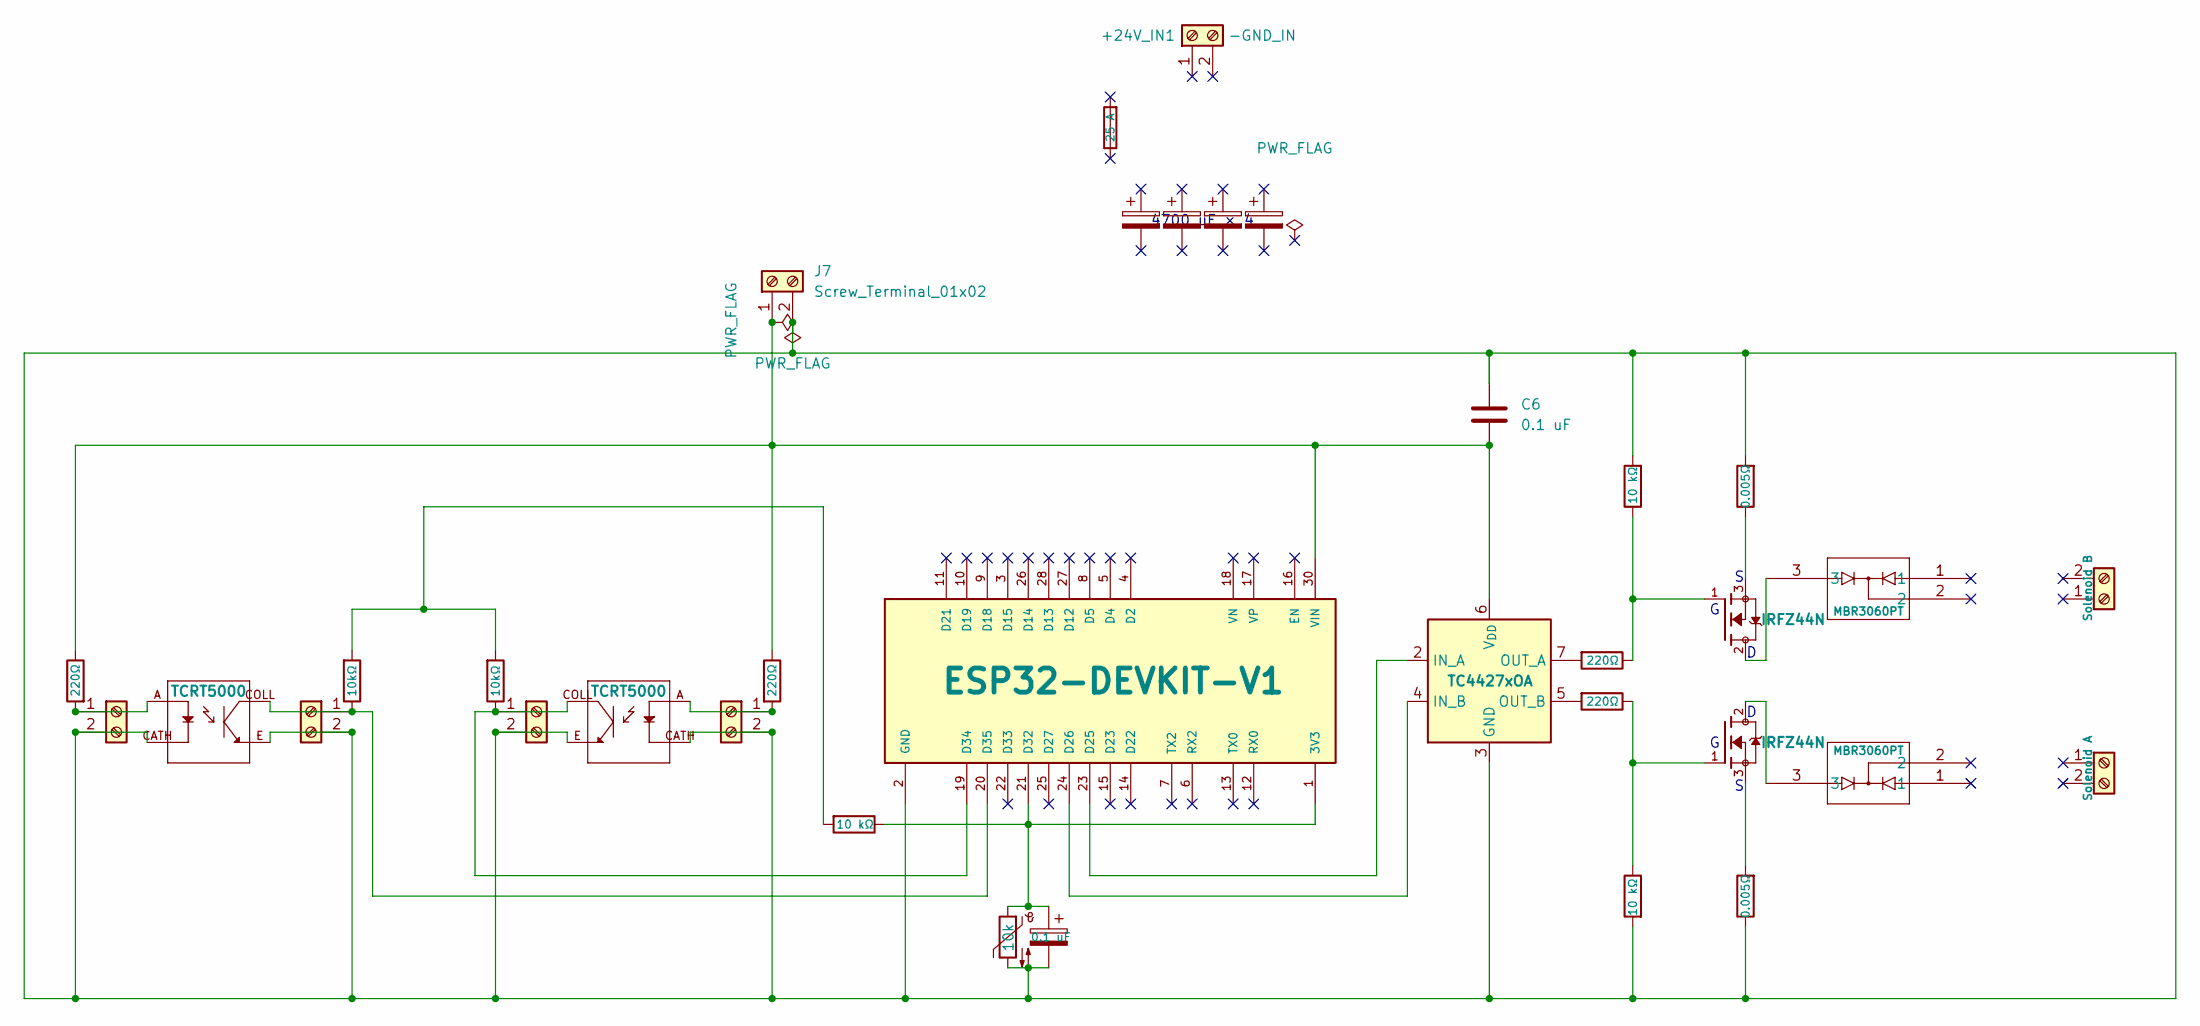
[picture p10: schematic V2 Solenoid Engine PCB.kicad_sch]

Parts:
+24V_IN1: -GND_IN; TerminalBlock_Phoenix_PT-1,5-2-5.0-H_1x02_P5.00mm_Horizontal
C1, C2, C3, C4: C_Polarized; CP_Radial_D16.0mm_P7.50mm
C5, C6: 0.1 uF; C_0805_2012Metric
CR1, CR2: MBR3060PT; TO-247-3LD_340CC_ONS
F1: 25 A; Fuseholder_Cylinder-5x20mm_Schurter_0031_8201_Horizontal_Op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
J1, J2, J3, J4: Screw_Terminal_01x02; TerminalBlock_Phoenix_MKDS-1,5-2_1x02_P5.00mm_Horizontal
J5: Solenoid B; TerminalBlock_Ningbo-Kagnex_HB9500M_1x02_P9.5mm
J6: Solenoid A; TerminalBlock_Ningbo-Kagnex_HB9500M_1x02_P9.5mm
J7: Screw_Terminal_01x02; TerminalBlock_Phoenix_PT-1,5-2-5.0-H_1x02_P5.00mm_Horizontal
Q1, Q2: IRFZ44N; TO-220-3_Vertical; PARTREV 09/21/10
R1, R2, R8, R11: 220Ω; R_Axial_DIN0207_L6.3mm_D2.5mm_P7.62mm_Horizontal
R3, R5, R7: 10 kΩ; R_Axial_DIN0207_L6.3mm_D2.5mm_P7.62mm_Horizontal
R4, R6: 0.005Ω; R_2512_6332Metric
R9, R10: 10kΩ; R_Axial_DIN0207_L6.3mm_D2.5mm_P7.62mm_Horizontal
TH1: 10k; R_Axial_DIN0207_L6.3mm_D2.5mm_P7.62mm_Horizontal
U1: ESP32-DEVKIT-V1; MODULE_ESP32_DEVKIT_V1; PARTREV N/A
U2: TC4427xOA; SOIC-8_3.9x4.9mm_P1.27mm
U5, U6: TCRT5000; Vishay_TCRT5000; PARTREV 1.7

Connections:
GND: C5.2, C6.1, J1.2, J2.2, J3.2, J4.2, J7.2, R3.2, R4.2, R5.2, R6.1, TH1.2, U1.2 (GND), U1.29 (GND), U2.3 (GND), U5.CATH, U5.E, U6.CATH, U6.E
unnamed: CR1.3, Q2.2
unnamed: CR2.3, Q1.2
unnamed: J1.1, R8.2, U6.A
unnamed: J2.1, R9.1, U1.19 (D34), U6.COLL
unnamed: J3.1, R11.2, U5.A
unnamed: J4.1, R10.1, U1.20 (D35), U5.COLL
unnamed: C6.2, J7.1, R8.1, R11.1, U1.30 (VIN), U2.6 (V_{DD})
unnamed: Q1.1, R1.1, R3.1
unnamed: Q1.3, R4.1
unnamed: Q2.1, R2.1, R5.1
unnamed: Q2.3, R6.2
unnamed: R7.2, R9.2, R10.2
unnamed: C5.1, R7.1, TH1.1, U1.1 (3V3), U1.21 (D32)
unnamed: U1.23 (D25), U2.2 (IN_A)
unnamed: U1.24 (D26), U2.4 (IN_B)
unnamed: R1.2, U2.7 (OUT_A)
unnamed: R2.2, U2.5 (OUT_B)

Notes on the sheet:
4700 uF × 4

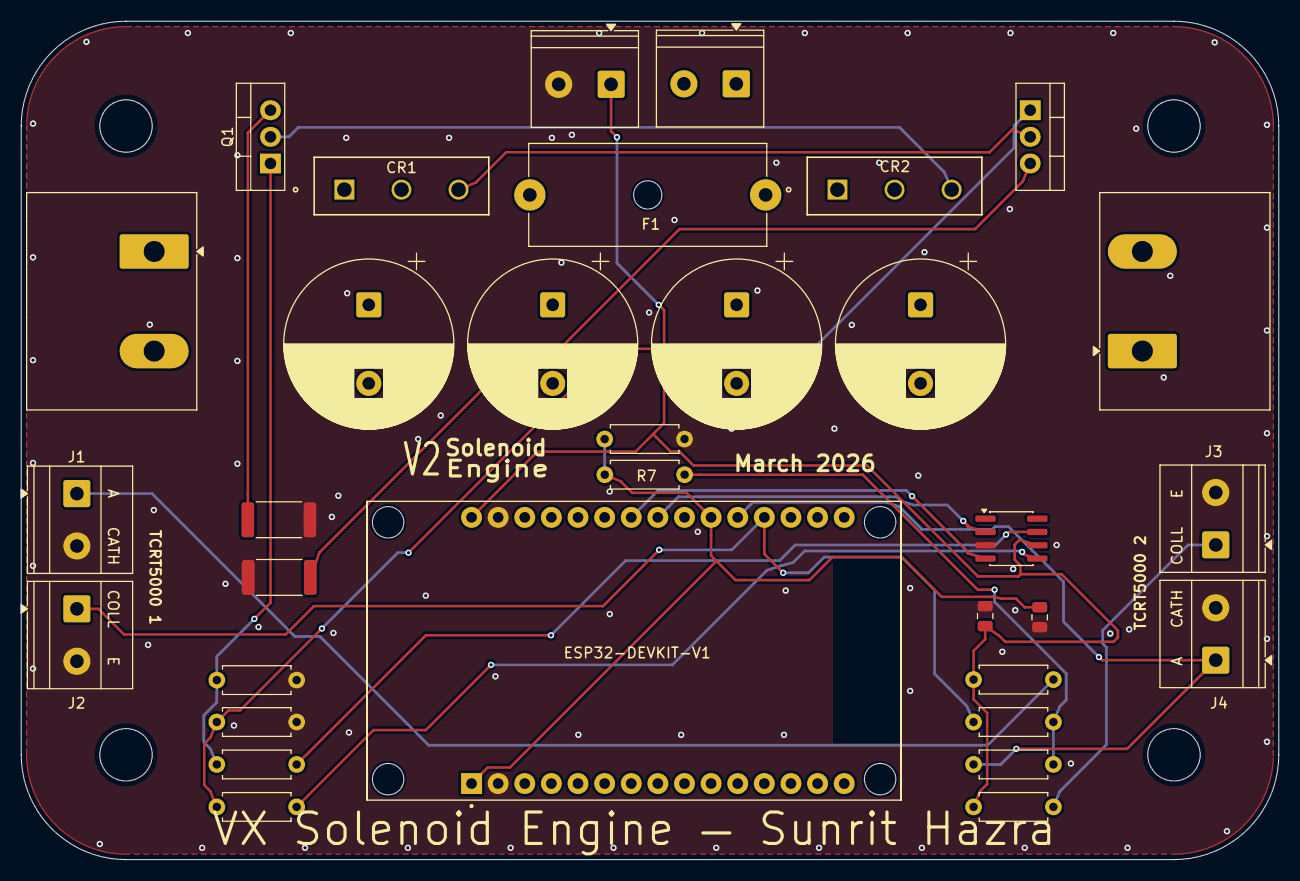
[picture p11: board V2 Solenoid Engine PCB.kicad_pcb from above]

Board: 2 copper layers, 120.0 x 80.0 mm, 33 parts (0 on the bottom side), 18 nets.

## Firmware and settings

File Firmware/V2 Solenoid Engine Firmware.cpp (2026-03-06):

/*
 * V2 Solenoid Engine ESP32 Firmware
 * 
 * Author: Sunrit Hazra (@SunritHazra)
 * Date: March 2026
 */

#include <WiFi.h>
#include <ESPAsyncWebServer.h>
#include <AsyncTCP.h>
#include <BluetoothSerial.h>

// Pin definitions (match your PCB)
#define PWM_PIN1 25      // Coil 1 PWM (GPIO25)
#define PWM_PIN2 26      // Coil 2 PWM (GPIO26)
#define SENSOR_PIN1 34   // TCRT5000 Sensor 1 (interrupt)
#define SENSOR_PIN2 35   // TCRT5000 Sensor 2 (interrupt)
#define TEMP_PIN 36      // NTC thermistor (ADC1_CH0)
#define BUTTON_PIN 0     // External power button (pull-up)

#define PWM_FREQ_MIN 1000  // Hz
#define PWM_FREQ_MAX 5000  // Hz
#define PWM_DUTY_MAX 40    // % (safety limit for no overheating)
#define TEMP_CUTOFF 80     // °C (thermal cutoff)

AsyncWebServer server(80);  // WiFi web server on port 80
BluetoothSerial SerialBT;   // Bluetooth Serial for debug

// Global variables
volatile bool trigger1 = false;  // Sensor 1 interrupt flag
volatile bool trigger2 = false;  // Sensor 2 interrupt flag
float dutyCycle = 20.0;          // Initial duty %
int pwmFreq = 2000;              // Initial frequency Hz
int advanceAngle = 15;           // Firing advance degrees (0-30)
bool engineOn = false;           // Master enable
float currentTemp = 0.0;         // Temperature °C

// PWM channels
const int pwmChannel1 = 0;
const int pwmChannel2 = 1;
const int pwmResolution = 8;     // 8-bit (0-255)

// WiFi AP credentials
const char* ssid = "Solenoid_AP";
const char* password = "engine123";

// Temperature calibration (NTC 10kΩ + 10kΩ divider, beta=3950, R25=10k)
float readTemperature() {
  int adcValue = analogRead(TEMP_PIN);
  float voltage = (adcValue / 4095.0) * 3.3;  // ESP32 ADC 12-bit, 3.3V ref
  float resistance = 10000.0 * (3.3 / voltage - 1.0);  // Divider formula
  float tempK = 1.0 / (1.0 / 298.15 + log(resistance / 10000.0) / 3950.0);  // Beta equation
  return tempK - 273.15;  // Celsius
}

// Interrupt service routines (ISR)
void IRAM_ATTR sensorISR1() {
  trigger1 = true;
}

void IRAM_ATTR sensorISR2() {
  trigger2 = true;
}

// PWM setup
void setupPWM() {
  ledcSetup(pwmChannel1, pwmFreq, pwmResolution);
  ledcSetup(pwmChannel2, pwmFreq, pwmResolution);
  ledcAttachPin(PWM_PIN1, pwmChannel1);
  ledcAttachPin(PWM_PIN2, pwmChannel2);
}

// Apply duty cycle to both channels (phased)
void updatePWM() {
  int dutyValue = (dutyCycle / 100.0) * 255;
  if (dutyValue > (PWM_DUTY_MAX / 100.0 * 255)) dutyValue = (PWM_DUTY_MAX / 100.0 * 255);  // Safety limit
  
  if (engineOn) {
    ledcWrite(pwmChannel1, dutyValue);  // Coil 1 on
    ledcWrite(pwmChannel2, 0);          // Coil 2 off (180° phase via sensors)
    delay(advanceAngle * 10);           // Simple advance delay (refine with encoder later)
    ledcWrite(pwmChannel1, 0);
    ledcWrite(pwmChannel2, dutyValue);  // Coil 2 on
  } else {
    ledcWrite(pwmChannel1, 0);
    ledcWrite(pwmChannel2, 0);
  }
}

// Web server handlers
void handleRoot(AsyncWebServerRequest *request) {
  String html = R"(
<!DOCTYPE html>
<html><head><title>Solenoid Engine Control</title>
<meta name='viewport' content='width=device-width, initial-scale=1'>
<style>body{font-family:Arial;margin:20px;background:#f0f0f0;} .slider{max-width:300px;}</style></head>
<body>
<h1>V2 Solenoid Engine Control</h1>
<p>Temp: )" + String(currentTemp, 1) + R"( °C | Status: )" + String(engineOn ? "ON" : "OFF") + R"(</p>
<label for='duty'>Duty Cycle (%): </label><input type='range' id='duty' min='0' max='40' value=)" + String(dutyCycle) + R"( onchange='sendValue("duty",this.value)'><span id='dutyVal'>)" + String(dutyCycle) + R"(</span><br>
<label for='freq'>Frequency (Hz): </label><input type='range' id='freq' min='1000' max='5000' value=)" + String(pwmFreq) + R"( onchange='sendValue("freq",this.value)'><span id='freqVal'>)" + String(pwmFreq) + R"(</span><br>
<label for='advance'>Advance Angle (°): </label><input type='range' id='advance' min='0' max='30' value=)" + String(advanceAngle) + R"( onchange='sendValue("advance",this.value)'><span id='advanceVal'>)" + String(advanceAngle) + R"(</span><br>
<button onclick='toggleEngine()'>)" + String(engineOn ? "STOP" : "START") + R"(</button>
<script>
function sendValue(param, value) {
  fetch('/set?'+param+'='+value).then(() => location.reload());
  document.getElementById(param+'Val').innerText = value;
}
function toggleEngine() {
  fetch('/toggle').then(() => location.reload());
}
setInterval(() => location.reload(), 2000);  // Refresh every 2s for temp/status
</script>
</body></html>
)";
  request->send(200, "text/html", html);
}

void handleSet(AsyncWebServerRequest *request) {
  if (request->hasParam("duty")) dutyCycle = request->getParam("duty")->value().toFloat();
  if (request->hasParam("freq")) pwmFreq = request->getParam("freq")->value().toInt();
  if (request->hasParam("advance")) advanceAngle = request->getParam("advance")->value().toInt();
  updatePWM();  // Immediate update
  request->send(200, "text/plain", "OK");
}

void handleToggle(AsyncWebServerRequest *request) {
  engineOn = !engineOn;
  updatePWM();
  request->send(200, "text/plain", engineOn ? "ON" : "OFF");
}

// Setup
void setup() {
  Serial.begin(115200);
  SerialBT.begin("Solenoid_BT");  // Bluetooth debug
  Serial.println("V2 Solenoid Engine Firmware Starting...");

  // Pin modes
  pinMode(SENSOR_PIN1, INPUT_PULLUP);
  pinMode(SENSOR_PIN2, INPUT_PULLUP);
  pinMode(BUTTON_PIN, INPUT_PULLUP);
  pinMode(TEMP_PIN, INPUT);

  // Interrupts for sensors (falling edge for trigger)
  attachInterrupt(digitalPinToInterrupt(SENSOR_PIN1), sensorISR1, FALLING);
  attachInterrupt(digitalPinToInterrupt(SENSOR_PIN2), sensorISR2, FALLING);

  // PWM setup
  setupPWM();

  // WiFi AP
  WiFi.softAP(ssid, password);
  Serial.print("WiFi AP IP: ");
  Serial.println(WiFi.softAPIP());

  // Web server routes
  server.on("/", HTTP_GET, handleRoot);
  server.on("/set", HTTP_GET, handleSet);
  server.on("/toggle", HTTP_GET, handleToggle);
  server.begin();

  // POST (power-on self-test)
  currentTemp = readTemperature();
  Serial.print("POST: Temp = ");
  Serial.print(currentTemp);
  Serial.println(" °C");
  updatePWM();  // Off initially
}

// Main loop
void loop() {
  // Read temperature every 500 ms
  static unsigned long lastTemp = 0;
  if (millis() - lastTemp > 500) {
    currentTemp = readTemperature();
    if (currentTemp > TEMP_CUTOFF) {
      engineOn = false;  // Thermal cutoff
      Serial.println("Thermal cutoff! Engine OFF.");
    }
    lastTemp = millis();
  }

  // Sensor triggering (phasing)
  if (trigger1) {
    trigger1 = false;
    // Advance logic: Fire coil 2 with advance
    delay(advanceAngle * 5);  // Simple delay-based advance (refine with timer)
    if (engineOn) ledcWrite(pwmChannel2, (dutyCycle / 100.0) * 255);
    delayMicroseconds(5000 / pwmFreq * 1000 * (dutyCycle / 100.0));  // On time
    ledcWrite(pwmChannel2, 0);
    SerialBT.println("Trigger1: Coil2 fired");
  }

  if (trigger2) {
    trigger2 = false;
    delay(advanceAngle * 5);
    if (engineOn) ledcWrite(pwmChannel1, (dutyCycle / 100.0) * 255);
    delayMicroseconds(5000 / pwmFreq * 1000 * (dutyCycle / 100.0));
    ledcWrite(pwmChannel1, 0);
    SerialBT.println("Trigger2: Coil1 fired");
  }

  // Button for soft power (optional)
  if (digitalRead(BUTTON_PIN) == LOW) {
    delay(50);  // Debounce
    if (digitalRead(BUTTON_PIN) == LOW) {
      engineOn = !engineOn;
      updatePWM();
      Serial.println(engineOn ? "Engine ON" : "Engine OFF");
    }
  }

  // Debug output
  if (Serial.available()) {
    String cmd = Serial.readString();
    cmd.trim();
    if (cmd == "status") {
      Serial.println("Duty: " + String(dutyCycle) + "%, Freq: " + String(pwmFreq) + "Hz, Temp: " + String(currentTemp) + "°C, On: " + String(engineOn));
    } else if (cmd.startsWith("duty ")) {
      dutyCycle = cmd.substring(5).toFloat();
      updatePWM();
    } // Add more commands...
  }
}

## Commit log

2026-03-08 Update V2 Bill of Materials.csv
    [V2 Bill of Materials.csv]
2026-03-27 Create Bill of Materials.md
2026-03-27 Rename V2 Bill of Materials.csv to V2 Solenoid Engine — Bill of Materials.csv
    [V2 Solenoid Engine — Bill of Materials.csv]
2026-03-27 Rename Bill of Materials.md to V2 Solenoid Engine — Bill of Materials.md
2026-03-27 Update V2 Solenoid Engine — Bill of Materials.md
2026-04-03 Rename V2 Solenoid Engine — Bill of Materials.csv to V2 Solenoid Engine — Bill of Materials [ORIGINAL].csv
    This is the original CSV submitted for grant request for Blueprint YSWS by Hack Club
    [V2 Solenoid Engine — Bill of Materials [ORIGINAL].csv]
2026-04-03 Update V2 Solenoid Engine — Bill of Materials [ORIGINAL].csv
    [V2 Solenoid Engine — Bill of Materials [ORIGINAL].csv]
